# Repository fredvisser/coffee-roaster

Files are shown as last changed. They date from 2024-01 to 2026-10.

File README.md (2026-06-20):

# DIY Hot Air Coffee Roaster

This repository is my latest attempt to make home coffee roasting simple, reliable, scientific, and affordable.

The tagged `v1` release preserves a legacy Nextion-based hardware design. This branch intentionally documents only the current controller, tooling, and firmware layout.

## Features

- PID temperature control with profile-based roast automation
- Dual MAX6675 thermocouple monitoring
- Integrated JC4827W543C touchscreen UI using LVGL
- Web console, REST API, and OTA firmware updates
- Artisan integration for roast logging
- Safety systems for over-temperature, sensor faults, and emergency shutdown

## Firmware Setup

For complete setup, build, and deployment instructions, see [roaster-firmware/README.md](roaster-firmware/README.md).

## Hardware Docs

Hardware assembly guidance and the project bill of materials should live at the repository root because they span the whole build, not just the firmware:

- [BUILD.md](BUILD.md) for the physical build and assembly workflow
- [BOM.md](BOM.md) for the parts list and sourcing notes

The tagged `v1` release remains the reference for the legacy hardware design. This branch should document only the current controller and any current-generation enclosure or PCB assets that are restored into the repository.

### Quick Start

```bash
git clone https://github.com/fredvisser/coffee-roaster.git
cd coffee-roaster/roaster-firmware
./tools/bootstrap.sh
./tools/firmware.sh build --board jc4827w543c
```

Canonical developer entrypoints:

- `./tools/bootstrap.sh`
- `./tools/firmware.sh`
- `./tools/tests.sh`

## Runtime Interfaces

- Web console: `http://roaster-dev.local/console`
- OTA update page: `http://roaster-dev.local/update`
- Profile editor: `http://roaster-dev.local/profile`
- PID workflow: `http://roaster-dev.local/pid`

## Roast Data and Artisan

The firmware can stream roast data to [Artisan](https://artisan-scope.org) over WebSockets. For setup and connection steps, see [ARTISAN.md](ARTISAN.md). The repository includes an Artisan settings file in `Artisan/`.

## Firmware REST API (summary)

For full details see roaster-firmware/README.md. Key endpoints (id-based):

- GET `/api/profiles` → `{ profiles: [{ id, name, active }], active: id }`
- POST `/api/profiles` → Create profile `{ name, setpoints?, activate? }` → returns `{ ok, id, name, setpoints }`
- GET `/api/profiles/:id` → `{ id, name, setpoints, active? }`
- PUT `/api/profiles/:id` → Update `{ name, setpoints, activate? }` (id from path wins)
- POST `/api/profiles/:id/activate` → Activate profile
- DELETE `/api/profiles/:id` → Delete (409 if active)

Notes:
- Times are seconds in API/UI; firmware stores milliseconds.
- Temp bounds 0–500°F; Fan bounds 0–100%.
- Names are display-only; storage is keyed by opaque ids.

## Artisan

For complete Artisan setup, settings import, and connection steps, see [ARTISAN.md](ARTISAN.md).

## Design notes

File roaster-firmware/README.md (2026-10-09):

# Coffee Roaster Firmware

ESP32-S3 JC4827W543C-based coffee roaster control system with PID temperature control, dual fan management, LVGL touchscreen UI, and web interfaces.

## Features

- **Temperature Control**: Dual MAX6675 thermocouple sensors with PID control
- **Heating Element**: PWM-controlled heating element (0-255 range)
- **Dual Fan Control**: 
  - PWM fan for bean agitation
  - BDC fan with servo control for air circulation
- **Local Display**: LVGL-based onboard touchscreen UI on the JC4827W543C panel
- **Network Features**: 
  - WiFi connectivity
  - WebSocket real-time monitoring
  - OTA firmware updates
  - mDNS discovery (roaster-dev.local)
- **Safety Systems**:
  - Thermal runaway protection
  - Over-temperature cutoff (500°F absolute, 460°F roasting)
  - Sensor failure detection
  - Emergency shutdown procedures
  - Hardware watchdog timer
- **Profile Management**: Custom roast profiles with time/temperature/fan curves
- **Persistent Debug Logs**: Appends JSON Lines to the onboard TF/microSD card when available

## Hardware Requirements

- JC4827W543C ESP32-S3 display board
- MAX6675 thermocouple amplifiers (x2)
- Heating element with PWM control circuit
- PWM fan
- BDC fan with servo control
- Integrated local display and touch hardware on the JC4827W543C board
- Optional FAT32-formatted microSD/TF card (8–32 GB)

### TF Card Logging

At boot, the firmware mounts the TF card over SPI using GPIO10 (CS), GPIO11 (MOSI), GPIO12 (clock), and GPIO13 (MISO). Debug entries are appended as JSON Lines with a boot ID and uptime in milliseconds. The active file is `/roaster-debug.jsonl`; up to four 1 MiB rotated segments are retained alongside it. Open `http://roaster-dev.local/console` and choose **Card History** to page through, filter, and download a segment. If the card is absent or cannot be written, the roaster continues using the RAM log buffer and Serial output. Card detection happens at boot, so insert a card before powering on.

## Building

### LVGL Simulator

You can render the display screens locally on macOS using the SDL-backed LVGL simulator:

```bash
brew install cmake pkg-config sdl2

cd roaster-firmware
./tools/lvgl-sim.sh run start
./tools/lvgl-sim.sh screenshot all
```

Screenshot output is written to `roaster-firmware/build/simulator-screens/` and can be inspected directly or shared back into Copilot for visual review.

### Quick Setup (Automated)

```bash
# 1. Navigate to firmware directory
cd roaster-firmware

# 2. Run automated setup script (installs all dependencies)
./tools/bootstrap.sh

# 3. Compile and upload firmware
./tools/firmware.sh upload

# Or just compile (creates .bin in build/ directory)
./tools/firmware.sh build
```

### Manual Setup

#### 1. Install Arduino CLI

```bash
brew install arduino-cli  # macOS
# or download from https://arduino.github.io/arduino-cli/
```

#### 2. Install ESP32 Core

```bash
arduino-cli config init
arduino-cli config add board_manager.additional_urls https://raw.githubusercontent.com/espressif/arduino-esp32/gh-pages/package_esp32_index.json
arduino-cli core update-index
arduino-cli core install esp32:esp32@3.3.11
```

#### 3. Install Required Libraries

```bash
arduino-cli lib install "MAX6675 library" "SimpleTimer" \
  "AutoPID" "ESP32Servo" "ElegantOTA@3.1.7" "ArduinoJson"
```

#### 4. Install AsyncWebServer Libraries (manual)

```bash
cd ~/Documents/Arduino/libraries
git clone https://github.com/ESP32Async/AsyncTCP.git
git clone https://github.com/ESP32Async/ESPAsyncWebServer.git
```

#### 5. Configure ElegantOTA for Async Mode ⚠️ IMPORTANT

ElegantOTA must be configured for async mode to work with ESPAsyncWebServer:

```bash
# Edit ~/Documents/Arduino/libraries/ElegantOTA/src/ElegantOTA.h
# Change: #define ELEGANTOTA_USE_ASYNC_WEBSERVER 0
# To:     #define ELEGANTOTA_USE_ASYNC_WEBSERVER 1

# Or use this one-liner:
sed -i '' 's/#define ELEGANTOTA_USE_ASYNC_WEBSERVER 0/#define ELEGANTOTA_USE_ASYNC_WEBSERVER 1/' ~/Documents/Arduino/libraries/ElegantOTA/src/ElegantOTA.h
```

The automated `./tools/bootstrap.sh` script handles this configuration automatically.

#### 6. Compile and Upload

```bash
# Compile
./tools/firmware.sh build --board jc4827w543c

# Upload
./tools/firmware.sh upload --board jc4827w543c
```

### Build Artifacts

Compiled firmware is automatically copied to `build/roaster-firmware.bin`:

```bash
# Compile firmware (automatically saves .bin to build/)
./tools/firmware.sh build
```

**Note:** `.bin` files are excluded from version control via `.gitignore`.

Builds use all detected CPU cores by default. Set `ROASTER_BUILD_JOBS` to tune
parallel compilation for a constrained machine, for example:

```bash
ROASTER_BUILD_JOBS=4 ./tools/firmware.sh build --board jc4827w543c
```

The firmware revision defaults to the current Git commit. Override it with
`ROASTER_BUILD_VERSION` when a release label or date is required.

## Over-The-Air (OTA) Updates

After initial USB flash, firmware can be updated wirelessly without physical access to the device.

### Accessing OTA Interface

1. Connect to the same WiFi network as the roaster
2. Navigate to: **`http://roaster-dev.local/update`**
   - Alternative: Use device IP address if mDNS doesn't work

### Uploading New Firmware

1. **Compile firmware** to generate `.bin` file:
   ```bash
  ./tools/firmware.sh build
   ```

2. **Access OTA interface** at `http://roaster-dev.local/update`

3. **Upload firmware**:
   - Click "Choose File" and select `build/roaster-firmware.bin`
   - Click "Update"
   - Device will automatically update and reboot (~30 seconds)

4. **Verify update**: Check version or timestamp in debug console

### OTA Best Practices

- ✅ Test firmware on bench hardware before OTA deployment
- ✅ Keep backup `.bin` files of known-good firmware
- ✅ Ensure stable WiFi connection during update
- ✅ Wait for device to fully reboot before reconnecting
- ⚠️ Never interrupt power during OTA update
- ⚠️ OTA updates preserve WiFi credentials and roast profiles

### Helper Scripts

- **`tools/bootstrap.sh`**: Automated dependency installation (arduino-cli required)
- **`tools/firmware.sh`**: Main firmware build, upload, OTA, and monitor entrypoint
  - `./tools/firmware.sh build` - Compile main firmware
  - `./tools/firmware.sh upload` - Compile and upload to a connected board
  - `./tools/firmware.sh run` - Compile, upload, and monitor
  - `./tools/firmware.sh build --board jc4827w543c` - Compile for the JC4827W543C target
- **`tools/tests.sh`**: Named test-suite entrypoint
  - `./tools/tests.sh compile safety` - Compile the safety suite
  - `./tools/tests.sh run pid` - Compile, upload, and monitor the PID suite
- **Legacy aliases**: `./setup_libraries.sh` and `./run_tests.sh` remain available during the transition

## Configuration

Key parameters in `roaster-firmware.ino`:
- `KP`, `KI`, `KD`: PID tuning constants
- `MAX_SAFE_TEMP`: Absolute temperature limit (500°F)
- `MAX_ROAST_TEMP`: Maximum roasting temperature (460°F)
- `COOLING_TARGET_TEMP`: Temperature to complete cooling (145°F)

## Project Structure

```
roaster-firmware/
├── roaster-firmware.ino    # Main firmware sketch
├── src/
│   ├── platform/           # Board config, shared roaster types, calibration types
│   ├── display/            # Display backend selection and adapters
│   ├── profiles/           # RoastProfile model and profile storage logic
│   ├── control/            # PID control, validation, and autotuning
│   ├── network/            # WiFi, OTA, and embedded web UIs
│   ├── integrations/       # External service integrations such as SystemLink
│   └── support/            # Shared support utilities
├── tools/                  # Canonical developer entrypoints
└── tests/                  # Unit and hardware tests
    ├── test_profiles/      # Profile interpolation tests
    ├── test_pid/           # PID controller tests
    ├── test_state_machine/ # State transition tests
    ├── test_safety/        # Safety system tests (CRITICAL)
    ├── hardware_validation/# Hardware-in-the-loop tests
  ├── test_step_response/ # Step response tuning tests
  ├── unit_tests/         # Test runner
  └── wifi_probe/         # Connectivity probe sketch
```

## Testing

Comprehensive test suite covering:
- Profile management and interpolation
- PID controller behavior and stability
- State machine transitions and safety interlocks
- **Critical safety features** (thermal runaway, over-temp, sensor faults)
- Hardware validation tests

```bash
# Show named test suites
./tools/tests.sh list

# Run a test suite
./tools/tests.sh run safety

# Or run individual test suites
./tools/tests.sh run safety --board jc4827w543c
```

See `tests/README.md` for complete testing documentation.

Compatibility note: `./run_tests.sh` and `./setup_libraries.sh` still work, but they now forward to the `tools/` entrypoints.

## Web Profile Editor

- Access at: `http://roaster-dev.local/profile`
- Features:
  - Drag-and-drop points on an interactive graph (time vs temperature)
  - Up to 10 setpoints, each with time (seconds), temperature (°F), fan (%)
  - Save named profiles to NVS; activate and delete from the UI
  - Lists saved profiles and highlights active one
  - Undo/Redo for edits (drag, add, remove, apply)
  - Snapping controls (toggle + step sizes for time/temperature)
  - Import/Export profiles as JSON files

### REST API (id-based)

- GET `/api/profiles`: List all saved profiles
  - Response: `{ profiles: [{ id, name, active }], active: id }`
- POST `/api/profiles`: Create a profile
  - Body: `{ name, setpoints?: [...], activate?: boolean }`
  - Response: `{ ok: true, id, name, setpoints }`
- GET `/api/profiles/:id`: Fetch a saved profile by id
  - Response: `{ id, name, setpoints, active?: boolean }`
- PUT `/api/profiles/:id`: Create/update a profile by id (id from path wins)
  - Body: `{ name, setpoints, activate?: boolean }`
  - Response: `{ ok: true, id, name, setpoints, active?: id }`
- POST `/api/profiles/:id/activate`: Activate a saved profile by id
  - Response: `{ ok: true, active: id, name }`
- DELETE `/api/profiles/:id`: Delete a saved profile (409 if active)

Notes:
- Times are seconds in API/UI; firmware stores milliseconds internally.
- Temp bounds: 0–500°F; Fan bounds: 0–100% (validated server-side).
- Names are display-only; storage is keyed by opaque ids (`pf_<id>` data, `pm_<id>` meta).
- Active profile id is stored under `preferences` key `active_profile_id` for boot-time load.

## Safety

⚠️ **This device controls high temperatures and line voltage.**

All code changes must pass safety tests:
- Thermal runaway protection
- Over-temperature cutoff
- Sensor validation
- Emergency stop capability
- Fail-safe defaults (heater OFF, fan ON)

**Never deploy untested code to hardware that will roast coffee unattended.**

## Documentation

- `../QUICKSTART.md` - Quick start guide
- `../OTA_SETUP.md` - OTA update configuration
- `../agents.md` - Development guidelines
- `tests/README.md` - Testing documentation
- `../CODE_REVIEW.md` - Code review findings and fixes

## Temperature Units

All temperatures in this firmware are in **Fahrenheit (°F)**. This is documented throughout the code to prevent confusion.

## License

See `../LICENSE` or repository root for licensing information.

## Contributing

1. Write tests for new features
2. Ensure all existing tests pass
3. Test safety features thoroughly
4. Update documentation
5. Submit pull request with test results

## Support

For issues, questions, or contributions, see the main repository README.

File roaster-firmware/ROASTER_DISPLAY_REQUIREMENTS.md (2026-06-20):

# Roaster Display Requirements

## Purpose

Define the operator-facing requirements for the onboard roaster display. This document covers the display workflows for roast setup, roast execution, cancellation, cooling, Wi-Fi setup, and profile viewing/selection.

## Scope

The display shall support these operating screens:

- Start
- Network
- Roasting
- Cooling
- Error
- Active Profile

The display requirements apply to any supported display backend. The operator experience should remain consistent whether the implementation is rendered on LVGL hardware or through any future local display backend.

## Design Principles

- The display is the primary local operator interface for starting, monitoring, and canceling a roast.
- The display shall prioritize safety-critical state changes over cosmetic updates.
- The display shall expose profile selection and final-temperature override locally, but full profile authoring remains outside the display UI.
- Local display actions shall not silently corrupt or permanently overwrite saved profiles.

## User Goals

- Select the desired roast profile.
- Review the active profile before starting.
- Set the roast final temperature for the upcoming roast.
- Start a roast from the display without needing the web UI.
- Watch roast progress and key telemetry during roasting.
- Cancel a roast and force a cooling transition.
- Stop cooling and return the machine to idle.
- Configure Wi-Fi credentials and confirm network status.
- Understand error and fault conditions from the display alone.

## Functional Requirements

### FR-1: Start Screen

- The Start screen shall be the default screen when the roaster is idle.
- The Start screen shall display the current bean temperature.
- The Start screen shall display the currently selected profile name.
- The Start screen shall display the configured network address or Wi-Fi status summary.
- The Start screen shall display the firmware revision.
- The Start screen shall display the roast final-temperature target that will be used if the operator starts a roast immediately.
- The Start screen shall provide controls to start a roast, open Wi-Fi configuration, and open the active-profile view.

### FR-2: Final Temperature Setting

- The display shall allow the operator to set or adjust the roast final temperature before starting a roast.
- The display shall show the current value at all times while the roaster is idle.
- The displayed value shall default to the active profile's final target when a profile is loaded or changed.
- The supported range shall be bounded to a safe configured range. The current firmware uses 0-500 F, and the display shall not allow values outside the enforced firmware range.
- Starting a roast shall use the displayed final temperature as the run-time stop target for that roast.
- The final-temperature adjustment shall be treated as a roast-session override unless the operator explicitly saves profile changes through a separate profile-editing flow.

### FR-3: Start Roast

- The display shall allow roast start only when the roaster is in an idle-ready state.
- The display shall block roast start when no valid profile is available.
- The display shall present an explicit error message if the operator attempts to start without a valid profile.
- When a roast is started, the display shall transition to the Roasting screen immediately.
- Starting a roast shall use the active profile for the temperature and fan trajectory.
- Starting a roast shall use the display-selected final-temperature target for roast completion logic.

### FR-4: Roasting Progress

- The Roasting screen shall show the current measured temperature.
- The Roasting screen shall show the current target temperature derived from the active profile.
- The Roasting screen shall show the configured final target temperature.
- The Roasting screen shall show roast progress in time or profile-progress terms.
- The Roasting screen shall show the commanded fan setting.
- The Roasting screen shall show additional run telemetry when available, including heater output, exhaust or fan temperature, and blower drive level.
- Telemetry shall refresh frequently enough for an operator to track roast progression without perceivable lag. A target of at least 1 Hz is required, with faster refresh preferred.

### FR-5: Cancel Roast

- The Roasting screen shall provide a cancel or stop control.
- Canceling a roast shall immediately stop active roast control and de-energize the heater.
- Canceling a roast shall transition the machine into Cooling rather than directly to Idle.
- The system shall record the roast as user-terminated for any downstream logging or reporting path.

### FR-6: Cooling

- The Cooling screen shall show that the roaster is in a cooling state.
- The Cooling screen shall continue to display current temperature.
- The Cooling screen shall show the cooling target or status.
- The Cooling screen shall show that cooling airflow is commanded to maximum or otherwise safe cooling output.
- The Cooling screen shall provide a control to stop cooling and return to Idle when the operator determines it is safe.

### FR-7: Wi-Fi Configuration

- The display shall provide a dedicated Wi-Fi configuration workflow.
- The Network screen shall expose editable fields for SSID and password.
- The Network screen shall provide an apply action.
- While a connection attempt is in progress, the display shall show a transient status such as Connecting.
- After a successful connection, the display shall show the resolved network access address or IP address.
- If no credentials are configured, the display shall show a clear no-network state rather than stale connection data.
- Wi-Fi credentials shall be persisted only after a successful connection attempt.
- Failed connection attempts shall not erase previously working credentials unless the operator explicitly replaces them successfully.

### FR-8: View Active Profile

- The display shall provide an Active Profile screen.
- The Active Profile screen shall show the active profile name.
- The Active Profile screen shall visualize the active roast profile curve.
- The Active Profile screen shall refresh the chart when the active profile changes or when the operator requests a refresh.
- The Active Profile screen shall provide a way to return to the screen for the current machine state.

### FR-9: Switch Profiles

- The display shall allow the operator to switch to the previous or next saved profile from the Active Profile screen.
- Profile switching shall be available only while the roaster is idle.
- Profile switching shall wrap around when the operator moves past the first or last saved profile.
- After a profile change, the display shall update the active profile label, final target temperature, and profile visualization.
- The newly selected profile shall become the active profile used for the next roast.

### FR-10: Error Handling

- The display shall provide a dedicated Error screen.
- The Error screen shall present a short, operator-readable fault message.
- The display shall transition to the Error screen for safety-critical faults such as sensor failure or over-temperature conditions.
- The error presentation shall take precedence over normal navigation until the system enters a safe state.

### FR-11: State-Aware Navigation

- The display shall return to the screen that matches the current machine state when the operator exits auxiliary flows.
- If the roaster is idle, the return destination shall be Start.
- If the roaster is roasting, the return destination shall be Roasting.
- If the roaster is cooling, the return destination shall be Cooling.
- If the roaster is faulted, the return destination shall be Error.

## Out of Scope

- Full roast-profile editing on the display.
- Importing or exporting profiles from the display.
- Advanced PID tuning workflows on the display.
- Historical roast analysis on the display.

## Non-Functional Requirements

- Touch interactions shall be operable with gloved or flour-dusted hands typical of a roasting environment.
- Primary actions such as Start, Stop, and Apply Wi-Fi shall remain visible and understandable without training.
- Safety-related commands shall not depend on network availability.
- The display shall remain usable during background Wi-Fi reconnect attempts.
- Screen transitions and telemetry updates shall not block control-loop timing or watchdog servicing.
- Any backend-specific limitation shall be treated as an implementation gap, not a reason to weaken the operator workflow defined here.

## Acceptance Scenarios

### AS-1: Start a roast with final-temperature override

- Given the roaster is idle and a valid profile is active
- When the operator changes the final temperature and presses Start
- Then the roast starts with the active profile
- And the Roasting screen appears immediately
- And the displayed final target matches the operator-selected override

### AS-2: Cancel an active roast

- Given the roaster is actively roasting
- When the operator presses Stop
- Then the heater output is forced off
- And the machine enters Cooling
- And the Cooling screen is shown

### AS-3: Configure Wi-Fi

- Given the roaster is idle
- When the operator opens the Network screen, enters SSID and password, and presses Apply
- Then the display shows Connecting while the connection is attempted
- And after success the display shows the current network address

### AS-4: Review and switch profiles

- Given the roaster is idle and multiple saved profiles exist
- When the operator opens the Active Profile screen and presses Next or Previous
- Then the active profile changes
- And the profile name, curve, and final target display update to match the new selection

## Implementation Notes

- The current firmware already models the required screens and actions in the display abstraction.
- The current firmware also supports local final-temperature override, profile visualization, idle-only profile cycling, roast stop to cooling, cooling stop to idle, and Wi-Fi credential application.
- A dedicated Network screen is part of the intended requirements even if a specific backend currently routes that action differently.

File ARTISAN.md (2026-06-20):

# Artisan Setup

Use this guide to connect the roaster to [Artisan](https://artisan-scope.org) for live roast logging over WebSockets.

The roaster firmware can stream roast data directly to Artisan once the device is on WiFi and the web interface is reachable.

## What You Need

- a running roaster with current firmware
- WiFi configured on the roaster
- Artisan installed on your computer
- the included settings file at `Artisan/artisan-settings.aset`

## Load The Included Settings

1. Install and open [Artisan](https://artisan-scope.org).
2. Load the included settings file from `Artisan/artisan-settings.aset` using **Help > Load Settings...**.
3. Confirm the loaded device configuration matches the roaster connection.

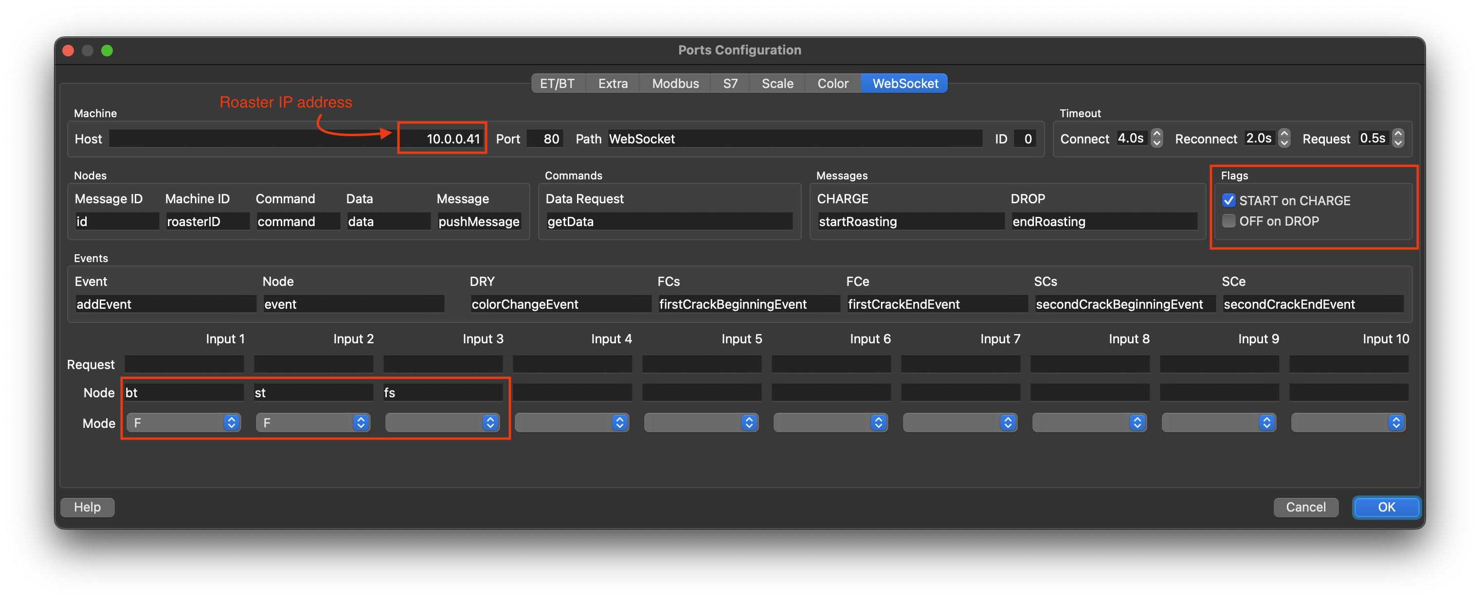
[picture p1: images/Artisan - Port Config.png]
Artisan port configuration


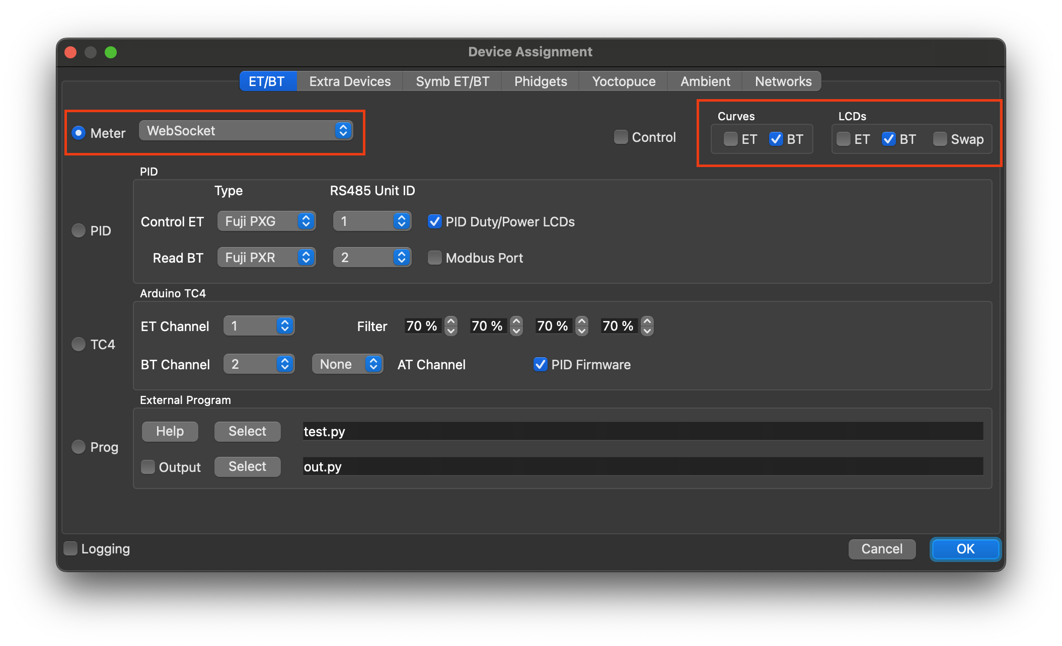
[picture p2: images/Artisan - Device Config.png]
Artisan device configuration


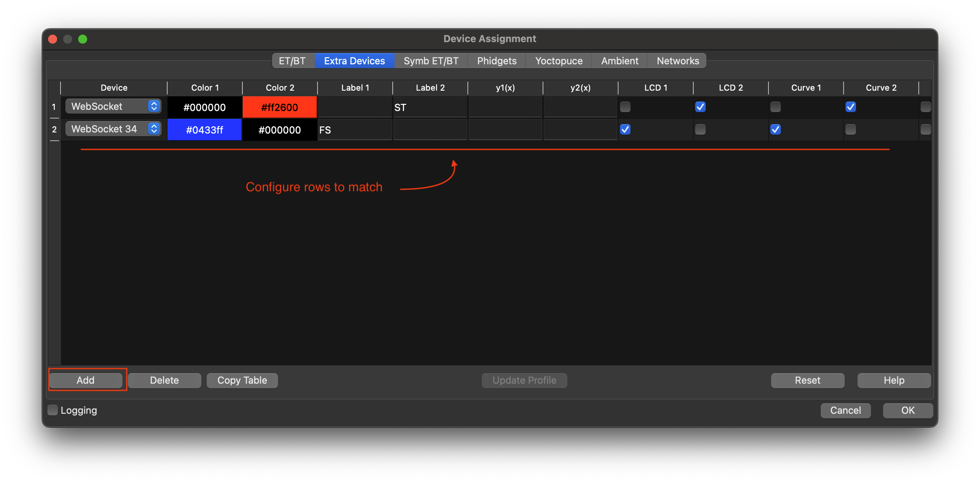
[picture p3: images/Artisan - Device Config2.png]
Artisan device configuration 2


## Connect To The Roaster

1. Make sure the roaster is powered on and connected to your network.
2. In Artisan, enable the connection with the **ON** button.
3. Confirm Artisan shows a successful WebSocket connection and starts receiving temperature data.

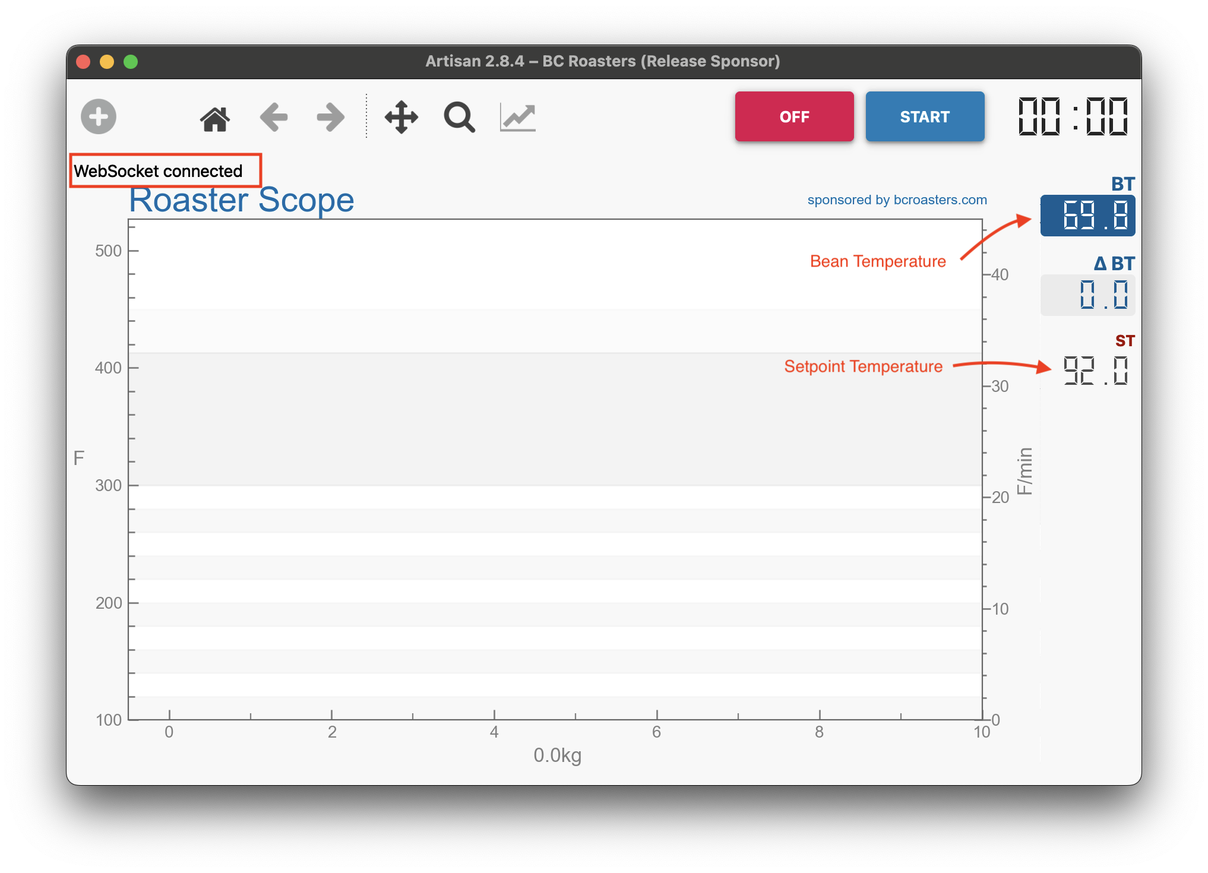
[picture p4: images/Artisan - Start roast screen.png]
Artisan start roast screen


## Start A Roast

1. Start the roast from the roaster UI.
2. Verify Artisan begins recording roast data automatically.
3. Watch the live curve and confirm bean and exhaust values look plausible.

## Troubleshooting

- If Artisan does not connect, verify the roaster web interface is reachable on your network first.
- If the connection succeeds but no useful data appears, confirm the correct settings file was loaded.
- If temperatures look unstable, check thermocouple wiring and the firmware web console before adjusting Artisan.

## Related Files

- [README.md](README.md) for the project overview
- [BUILD.md](BUILD.md) for hardware assembly
- [roaster-firmware/README.md](roaster-firmware/README.md) for firmware workflows

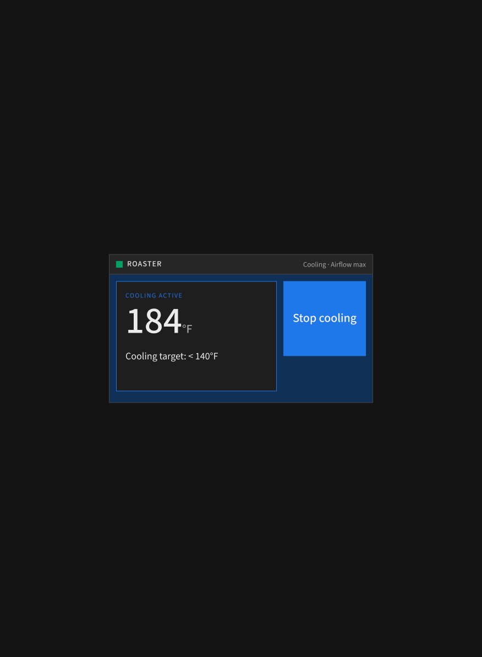
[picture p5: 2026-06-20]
figma-designs/cooling-screen.png

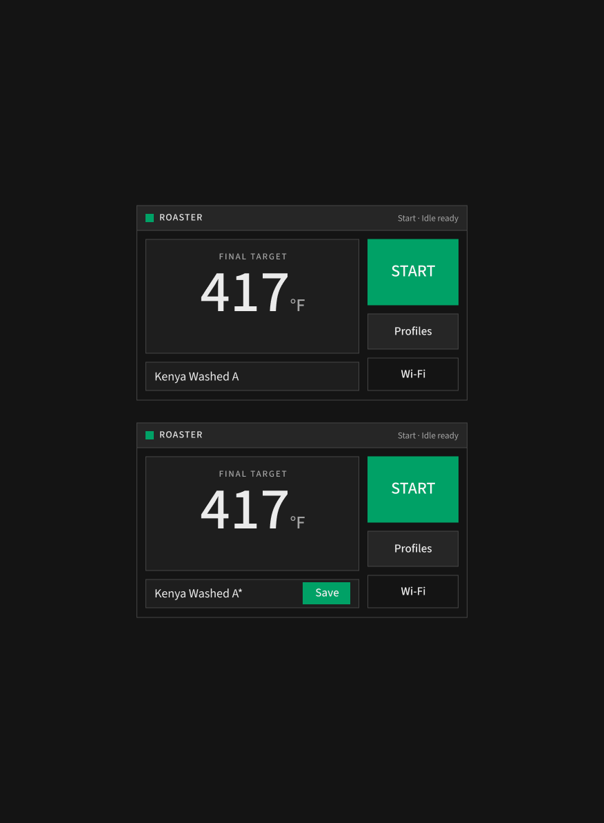
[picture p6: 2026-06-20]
figma-designs/main-screen.png

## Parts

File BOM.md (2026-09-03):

# Bill of Materials

This document is the home for the parts list for the current coffee roaster design.

## Scope

This file describes only the current branch hardware. Legacy parts lists should stay with the tagged `v1` release.

## Build Variants

There are two valid airflow build options for this design.

### Option A: Stock Popper Fan Motor

Use the stock popper fan motor when you want the simplest mechanical build.

- Use a 24 V power supply.
- Use a DC speed controller in the fan power path.
- Connect that speed-control path to the firmware-controlled fan PWM output.

### Option B: Custom Brushless Fan Conversion

Use the custom fan path when replacing the stock motor and fan hardware.

- Print the replacement fan and fan mount in ASA.
- Use a 12 V power supply.
- Use a brushless DC motor and matching controller.
- Treat the custom fan hardware, motor, controller, and 12 V supply as a matched set.

The tables below call out which parts apply to both options and which ones are specific to only one variant.

## Controller And Display Hardware

| Item | Qty | Description | Role | Amazon | AliExpress | Notes |
| --- | ---: | --- | --- | --- | --- | --- |
| JC4827W543C board | 1 | ESP32-S3 display controller with integrated LCD and touch | Main controller and local UI | [Amazon](https://www.amazon.com/dp/B0GTS9XSB4) | [AliExpress](https://www.aliexpress.us/item/3256806543063048.html) | Replaces the old Nano plus Nextion split; verify the capacitive-touch variant, pinout, and onboard memory before ordering |
| Roaster Breakout PCB | 1 | Breakout board from `PCBs/Roaster Breakout/` | Wiring distribution and mounting | N/A | N/A | Message me on Github and I'll mail you one. Alternatively, use `Roaster Breakout.brd` and `Roaster Breakout.sch`, or build the breakout on perf board instead |
| Perf board fallback | 1 | Generic through-hole prototyping board | Manual breakout-board build option | [Amazon](https://www.amazon.com/dp/B072Z7Y19F?ref=ppx_yo2ov_dt_b_fed_asin_title) | TBD | Use this only if not ordering or fabricating a dedicated breakout PCB |
| MAX6675 thermocouple module | 2 | K-type thermocouple amplifier module | Bean and exhaust sensing | [Amazon](https://www.amazon.com/dp/B092ZCSM7J) | [AliExpress](https://www.aliexpress.us/item/3256806044229155.html) | Firmware expects two channels |
| JC IO MX1.25 harness parts | Assorted | 4-pin MX1.25 board-side and harness-side connector parts, with pre-crimped leads | Connects to JC4827W543C I/O | [MX1.25-compatible pre-crimped lead set](https://www.amazon.com/Ssighuyx-Dupont2-54-Connector-Pre-Crimped-Compatible/dp/B0CMZHT1H9) | [MX1.25-compatible connector set](https://www.aliexpress.us/item/3256806948773358.html) | The JC I/O connector is MX1.25, not JST 1.25 or JST GH; verify the pin count, housing/keying, and lead length before ordering |

## Power Electronics

| Item | Qty | Description | Role | Amazon | AliExpress | Notes |
| --- | ---: | --- | --- | --- | --- | --- |
| 24 V power supply | 1 | Main low-voltage supply | Required for the stock popper fan motor build | TBD | [AliExpress](https://www.aliexpress.us/item/3256805366654681.html) | Option A only |
| 12 V power supply | 1 | Main low-voltage supply for custom fan conversion | Powers the brushless fan path | [Amazon](https://www.amazon.com/dp/B078RY6YY3?ref=ppx_yo2ov_dt_b_fed_asin_title) | [AliExpress](https://www.aliexpress.us/item/3256805366654681.html) | Option B only; confirm the ordered voltage and current variant |
| DC-DC converter or regulator | 1 | Secondary low-voltage conversion stage | Supplies any required rail below the main supply voltage | TBD | TBD | Keep exact part aligned with the restored current board design |
| Heater SSR | 1 | AC-output solid-state relay | Controls heater power | [Amazon](https://www.amazon.com/SSR-25DA-3-32VDC-Output-24-480VAC-Plastic/dp/B08GPJ1V2J) | [AliExpress](https://www.aliexpress.us/item/2255800713623525.html) | Must be correctly rated for mains and heater load |
| DC speed controller for stock fan motor | 1 | MOSFET-based DC motor speed controller | Controls the stock popper fan motor path from the PWM-controlled output | [Amazon](https://www.amazon.com/Anmbest-High-Power-Adjustment-Electronic-Brightness/dp/B07NWD8W26) | TBD | Option A only; select a specific controller listing after confirming the stock motor voltage and current |
| Power inlet or socket assembly | 1 | Enclosed mains input | Safe power entry | [Amazon](https://www.amazon.com/dp/B07PVP8CLT?ref_=ppx_hzsearch_conn_dt_b_fed_asin_title_31&th=1) | TBD | The popper lamp cord can be reused for outlet, switch, and power-supply wiring |
| Power switch | 1 | Panel-style rocker or toggle switch | Main power control | [Amazon](https://www.amazon.com/dp/B09YCG3NM1?ref=ppx_yo2ov_dt_b_fed_asin_title) | TBD | Clip off the flexible plastic tabs and super glue the switch to the case to avoid overstressing the printed enclosure |

## Sensors And Wiring

| Item | Qty | Description | Role | Amazon | AliExpress | Notes |
| --- | ---: | --- | --- | --- | --- | --- |
| K-type thermocouple | 2 | Temperature probes | Bean and exhaust temperature measurement | [Amazon](https://www.amazon.com/dp/B092ZCSM7J?ref=ppx_yo2ov_dt_b_fed_asin_title) | [AliExpress](https://www.aliexpress.us/item/3256806044229155.html) | Carefully hacksaw roughly 3/16 in off the tip to expose the junction so the probe responds faster to moving air |
| Silicone wire | Assorted | High-temp flexible wire | Heater and fan rewiring | [Amazon](https://www.amazon.com/dp/B07FMLVF84?ref=ppx_yo2ov_dt_b_fed_asin_title) | [AliExpress](https://www.aliexpress.us/item/2255800441309579.html) | Use the popper lamp cord for outlet, switch, and supply wiring; use higher-temp silicone wire for motor and heater wiring |
| Splice or crimp connectors | Assorted | Inline electrical splice terminals | Joins motor, heater, and supply wiring | [Amazon](https://www.amazon.com/dp/B0CJ5QF3VX?ref=ppx_yo2ov_dt_b_fed_asin_title) and [Amazon](https://www.amazon.com/Feggizuli-Connectors-Connector-Terminals-Electrical/dp/B0B4H54KPS) | TBD | Use these or equivalent crimp connectors where removable or insulated splices are needed |
| Heat shrink tubing | Assorted | Wire insulation and strain relief | Safer harness construction | TBD | TBD | Use on all splices and terminations where practical |

## Airflow And Load Hardware

| Item | Qty | Description | Role | Amazon | AliExpress | Notes |
| --- | ---: | --- | --- | --- | --- | --- |
| 1200 W popcorn popper | 1 | Upright hot-air popcorn popper with a clear upper chamber and side switch | Core roasting hardware | [Amazon](https://a.co/d/01RdS3ub) | TBD | Modified for external heater and fan control. If this listing is out of stock, find another hot-air popper that looks the same. |
| Stock popper fan motor | 1 | Original motor retained from the popper | Airflow source | Included with popper | N/A | Option A only |
| Brushless DC motor and controller | 1 set | Replacement motor and matched driver | Airflow source for custom fan conversion | [Amazon](https://www.amazon.com/dp/B075ZSDR2T?ref=ppx_yo2ov_dt_b_fed_asin_title) | TBD | Option B only |

## Mechanical And Printed Parts

| Item | Qty | Description | Role | Amazon | AliExpress | Notes |
| --- | ---: | --- | --- | --- | --- | --- |
| Enclosure Bottom.stl | 1 | Main lower enclosure body | Supports popper base and internal hardware | N/A | N/A | Current filename in `3D printing/` |
| Enclosure Top.stl | 1 | Upper enclosure shell | Covers and protects internal hardware | N/A | N/A | Current filename in `3D printing/` |
| Handle - Main.stl | 1 | Main carrying handle | Mechanical handling | N/A | N/A | Current filename in `3D printing/` |
| Handle - Trim.stl | 1 | Cosmetic or fit trim for handle | Finish and fit | N/A | N/A | Current filename in `3D printing/` |
| 12V - Power Supply Mount.stl | 1 | Printed mount for the power supply | Internal mechanical support | N/A | N/A | Current filename in `3D printing/`; verify fit for the selected supply |
| Breakout Mount.stl | 1 | Printed mount for the breakout board | Supports controller-side hardware | N/A | N/A | Current filename in `3D printing/` |
| Feet.stl | 1 set | Printed feet | Stability and surface protection | N/A | N/A | Current filename in `3D printing/`; TPU is still a good default |
| BDC Fan Mount.stl | 1 | Printed fan mount for the custom airflow option | Supports the brushless motor conversion | N/A | N/A | Option B only |
| Fan.stl | 1 | Printed fan for the custom airflow option | Airflow hardware for the brushless conversion | N/A | N/A | Option B only; print in ASA |
| Roaster Enclosure v2.3mf | 1 | Combined enclosure project file | Print preparation and fit reference | N/A | N/A | Use this to inspect the assembled print set before slicing |
| Roaster Breakout.brd and Roaster Breakout.sch | 1 set | Current breakout board design files | Board fabrication and reference | N/A | N/A | Located in `PCBs/Roaster Breakout/` |

## Fasteners And Consumables

| Item | Qty | Description | Role | Amazon | AliExpress | Notes |
| --- | ---: | --- | --- | --- | --- | --- |
| M3 fastener kit | 1 set | Assorted M3 screws, nuts, and standoffs | Standard enclosure and electronics fasteners | [M3 fastener set](https://www.amazon.com/dp/B097Y6KCVW?ref_=ppx_hzsearch_conn_dt_b_fed_asin_title_3) | TBD | Use M3 hardware as the standard fastener set wherever practical |
| M4 nuts and bolts | Assorted | Popper base and enclosure mounting hardware | Mechanical attachment of the popper assembly | TBD | TBD | Legacy assembly used M4 hardware through the enclosure bottom |
| Heat shrink and cable management | Assorted | Insulation and strain relief | Safer wiring | TBD | TBD | Strongly recommended |
| Super glue or equivalent adhesive | As needed | Adhesive for low-load mounting tasks | Switch and trim attachment | TBD | TBD | Use to mount the power switch after clipping the plastic tabs; use only where heat exposure is acceptable |

## Remaining Gaps

The core v2 parts list is in place, but a few sourcing fields still need confirmation before this BOM is fully complete:

- remaining Amazon and AliExpress links still marked `TBD`
- final quantities for connectors, heat shrink, and some fasteners
- any additional board-fabrication outputs you want listed beyond `Roaster Breakout.brd` and `Roaster Breakout.sch`

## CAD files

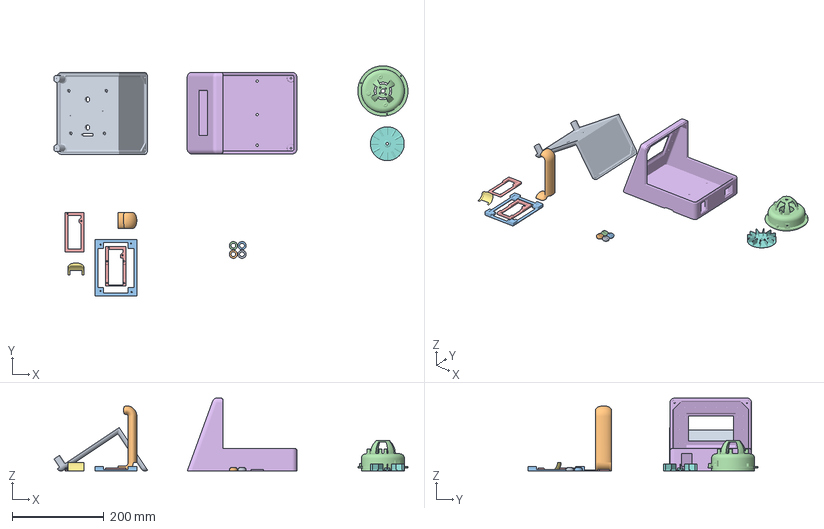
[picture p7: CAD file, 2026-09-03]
3D printing/Roaster Enclosure v2.3mf
770.8 x 501.4 x 158.8 mm
Enclosure Top
Handle - Main.step.stl
12V - Power Supply Mount - 12V - Power supply mount.step
Part Studio 1 - Part 1-58.step
Breakout Mount - Perfboard.step
Enclosure - Enclosure Bottom-2.step
Handle - Trim.stl
Part Studio 1 - Fan-7.step
Feet.stl x 4
Breakout mount - PCB

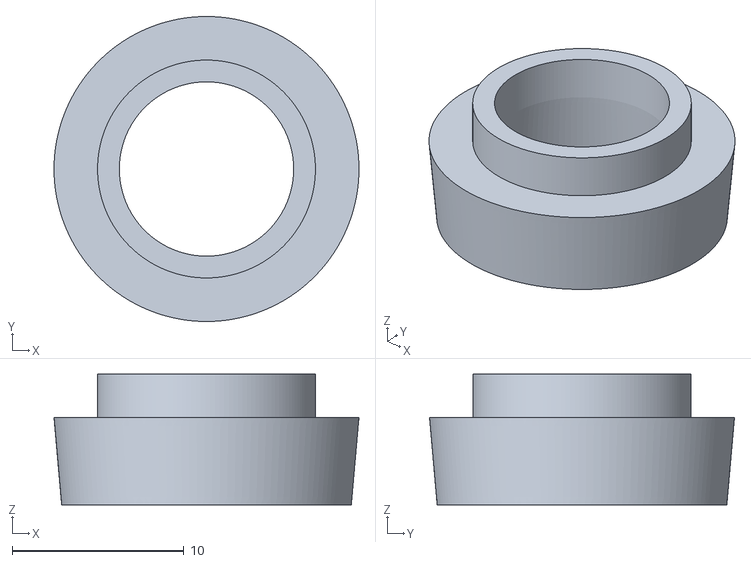
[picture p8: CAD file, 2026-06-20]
3D printing/Feet.stl
17.8 x 17.8 x 7.62

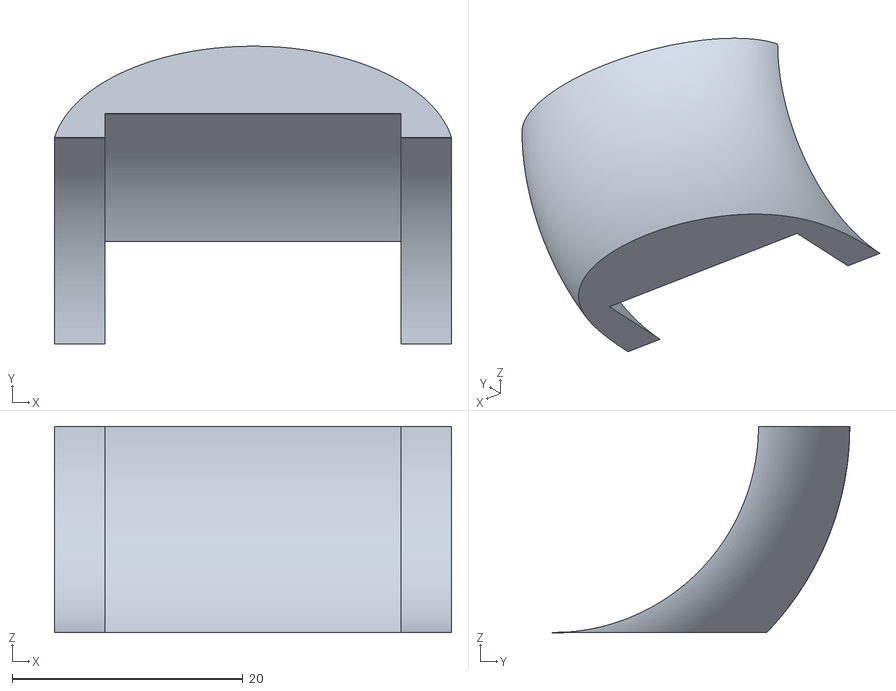
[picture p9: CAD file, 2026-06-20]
3D printing/Handle - Trim.stl
34.4 x 25.8 x 17.9

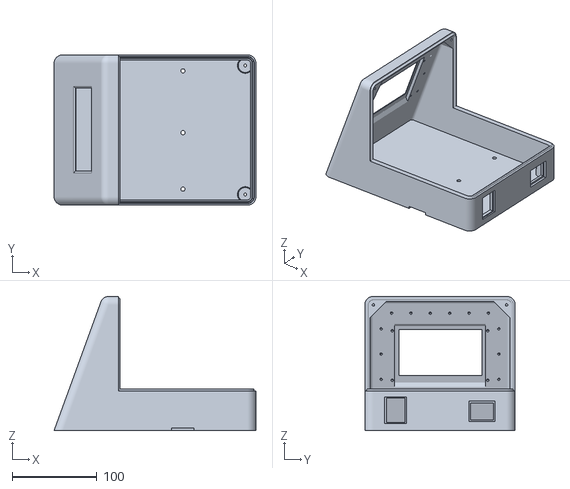
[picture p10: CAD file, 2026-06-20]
3D printing/Enclosure Bottom.stl
238.8 x 177.8 x 158.8

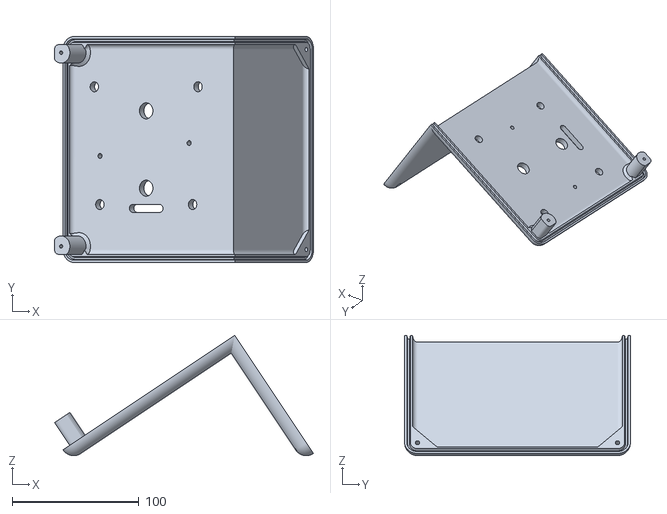
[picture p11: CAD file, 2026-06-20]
3D printing/Enclosure Top.stl
203.9 x 177.8 x 94.7

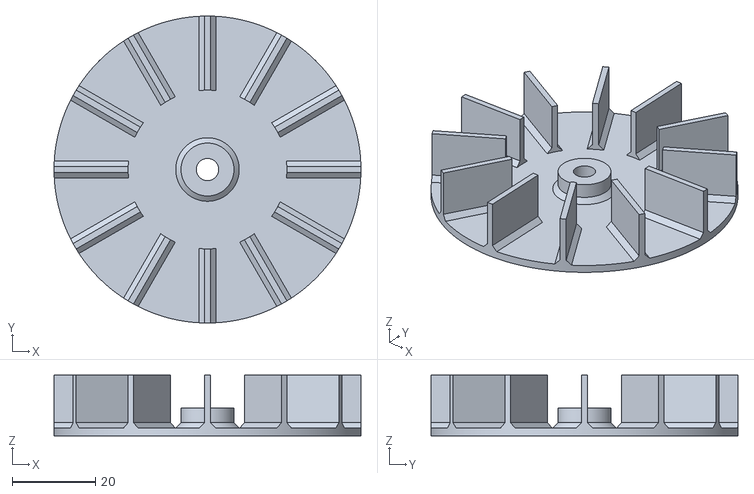
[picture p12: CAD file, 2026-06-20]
3D printing/Fan.stl
73.7 x 73.7 x 14.6

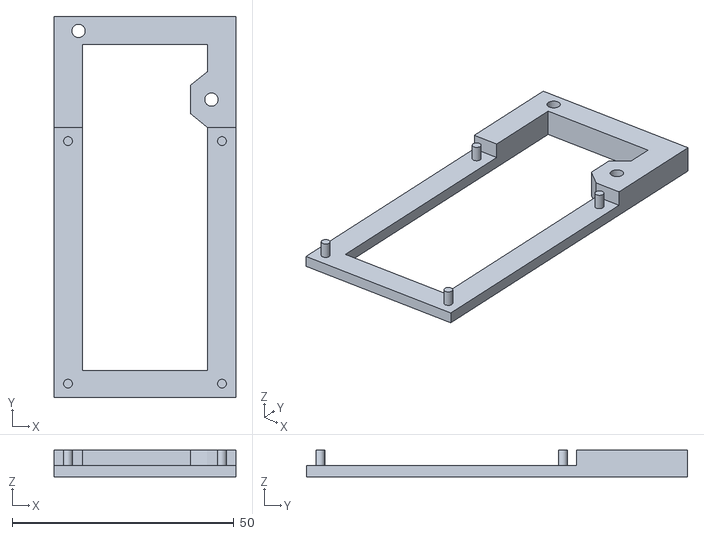
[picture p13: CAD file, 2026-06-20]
3D printing/Breakout Mount.stl
41.0 x 86.0 x 6.00

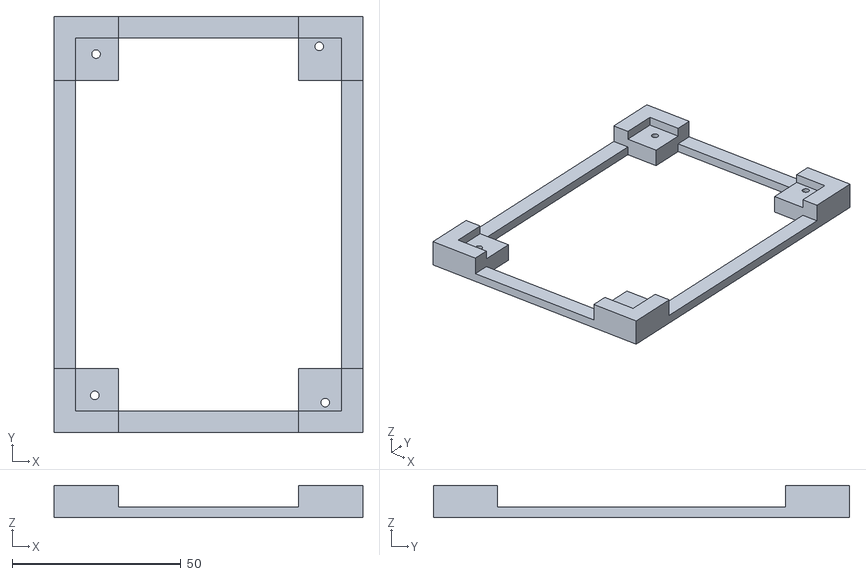
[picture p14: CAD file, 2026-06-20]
3D printing/12V - Power Supply Mount.stl
91.4 x 123.2 x 9.52

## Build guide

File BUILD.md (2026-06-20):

# Hardware Build Guide

Use this guide to assemble the current JC4827W543C-based coffee roaster. Use [BOM.md](BOM.md) for the parts list and sourcing links. Use [roaster-firmware/README.md](roaster-firmware/README.md) for firmware installation, OTA updates, and test workflows.

## Before You Start

This project combines mains voltage, high temperatures, and moving parts. Build it only if you are comfortable with basic electrical work and safe mains wiring practices.

- Never power the heater unattended.
- Keep mains wiring separated from low-voltage wiring.
- Use insulated connectors, heat shrink, and an enclosed mains inlet.
- Verify heater-off fail-safe behavior before the first roast.
- Keep a fire extinguisher nearby during bring-up and testing.

## Choose Your Fan Build

You need to decide which airflow build you are making before ordering parts or wiring the controller.

### Option A: Stock Popper Fan Motor

Choose this if you want the simplest mechanical build.

- Keep the stock popper fan motor.
- Use a 24 V power supply.
- Use the DC speed controller listed in [BOM.md](BOM.md).
- Connect the speed controller to the firmware-controlled fan PWM output.

### Option B: Custom Brushless Fan Conversion

Choose this if you want to replace the stock fan hardware.

- Print the replacement fan and fan mount in ASA.
- Use a 12 V power supply.
- Use the brushless DC motor and controller listed in [BOM.md](BOM.md).
- Treat the fan, mount, motor, controller, and 12 V supply as one matched system.

## What You Are Building

The current roaster uses:

- a JC4827W543C ESP32-S3 display board for the controller and touchscreen UI
- two MAX6675 thermocouple modules for bean and exhaust temperature
- one popcorn popper modified for separate heater and fan control
- one AC SSR in the heater path
- one main low-voltage supply, either 24 V or 12 V depending on the fan build

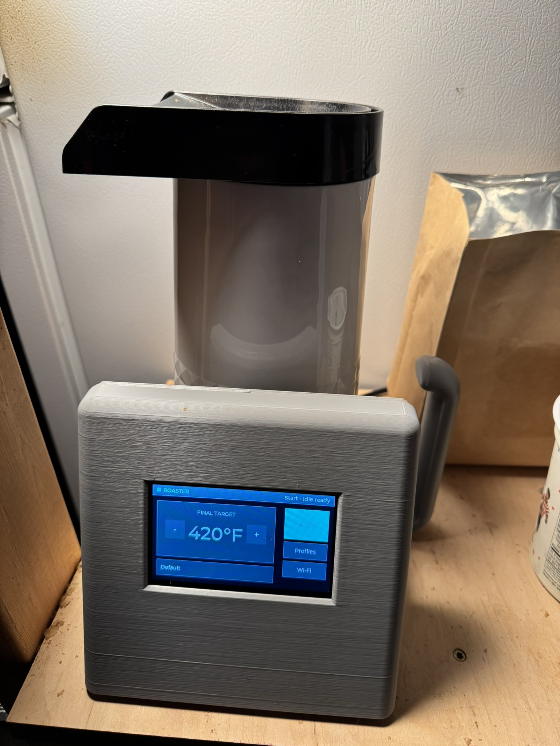
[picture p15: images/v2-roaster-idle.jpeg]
Assembled roaster

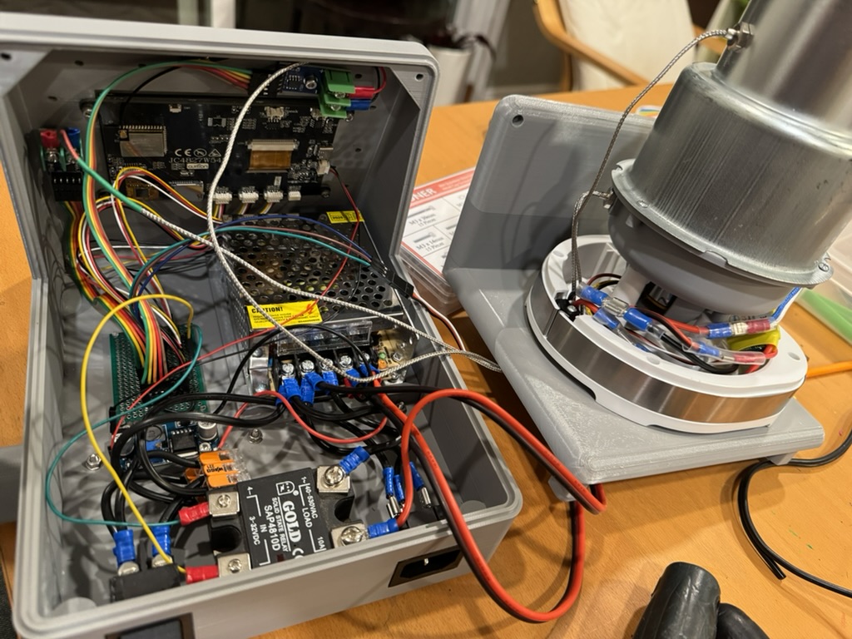
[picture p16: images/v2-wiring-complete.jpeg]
Assembled roaster internals


## Tools And Consumables

Have these on hand before starting:

- screwdrivers, hex keys, pliers, and flush cutters
- soldering iron and solder
- drill and bits for thermocouple and mounting holes
- heat shrink and crimp or splice connectors
- silicone-insulated wire for heater and fan rewiring
- super glue for the power switch and other light-duty mounting tasks
- fasteners and printed parts from [BOM.md](BOM.md)

## Step 1: Print The Parts

Print or obtain the enclosure parts before modifying the popper.

Print the parts from the `3D printing/` folder. The current filenames are:

- `Enclosure Bottom.stl`
- `Enclosure Top.stl`
- `Handle - Main.stl`
- `Handle - Trim.stl`
- `12V - Power Supply Mount.stl`
- `Breakout Mount.stl`
- `Feet.stl`
- `BDC Fan Mount.stl`
- `Fan.stl`
- `Roaster Enclosure v2.3mf`

Recommended materials:

- PLA for enclosure parts away from concentrated heat
- TPU for feet
- ASA for the custom fan and fan mount if you are building Option B

Use `Roaster Enclosure v2.3mf` as the assembled project file if you want to inspect the overall print set before slicing individual STL files.

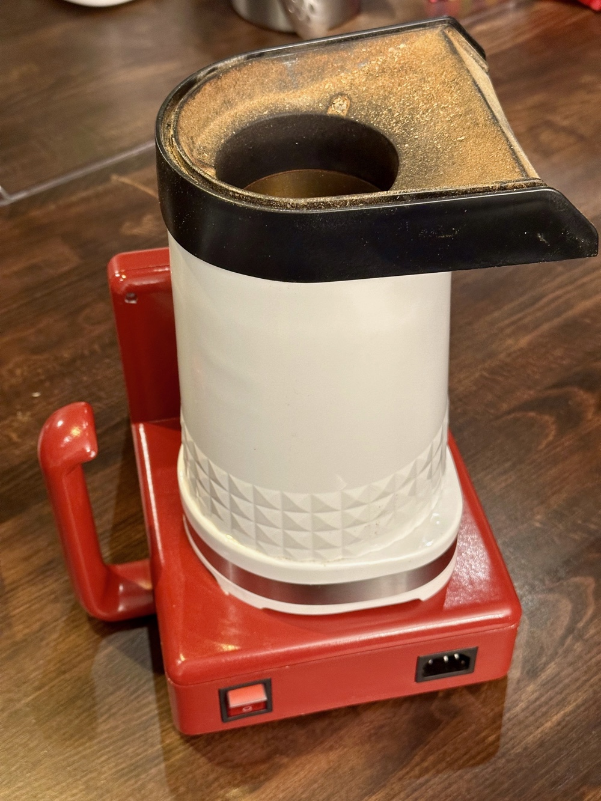
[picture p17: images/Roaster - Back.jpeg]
Roaster back view


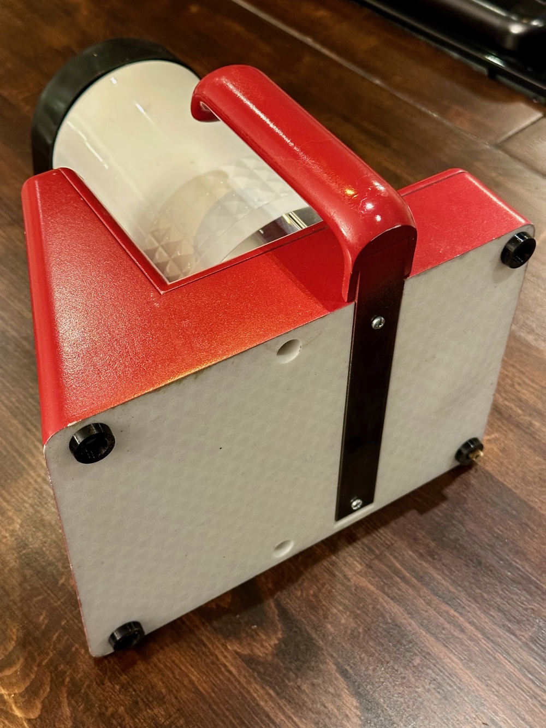
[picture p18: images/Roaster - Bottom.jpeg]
Roaster bottom view


Before moving on, test fit the display opening, mounting bosses, power supply mount, and wire-routing paths.

## Step 2: Build The Controller Hardware

Assemble the controller-side hardware next.

You will need:

- the JC4827W543C display board
- two MAX6675 modules
- the heater SSR
- the selected fan-control hardware for your build option
- the mains inlet and power switch
- the low-voltage power supply
- either the project breakout PCB or a perf-board equivalent

The breakout-board files currently in the repository are:

- `PCBs/Roaster Breakout/Roaster Breakout.sch`
- `PCBs/Roaster Breakout/Roaster Breakout.brd`
- `PCBs/Roaster Breakout/Breakout Perfboard.diy`

Mount the controller components so that:

- the display board is secure and accessible
- the thermocouple modules are reachable for wiring and service
- the heater control path is clearly separated from signal wiring
- the low-voltage supply and breakout hardware have adequate clearance

If you are making a breakout board on perf board, finish that assembly before starting the enclosure wiring.

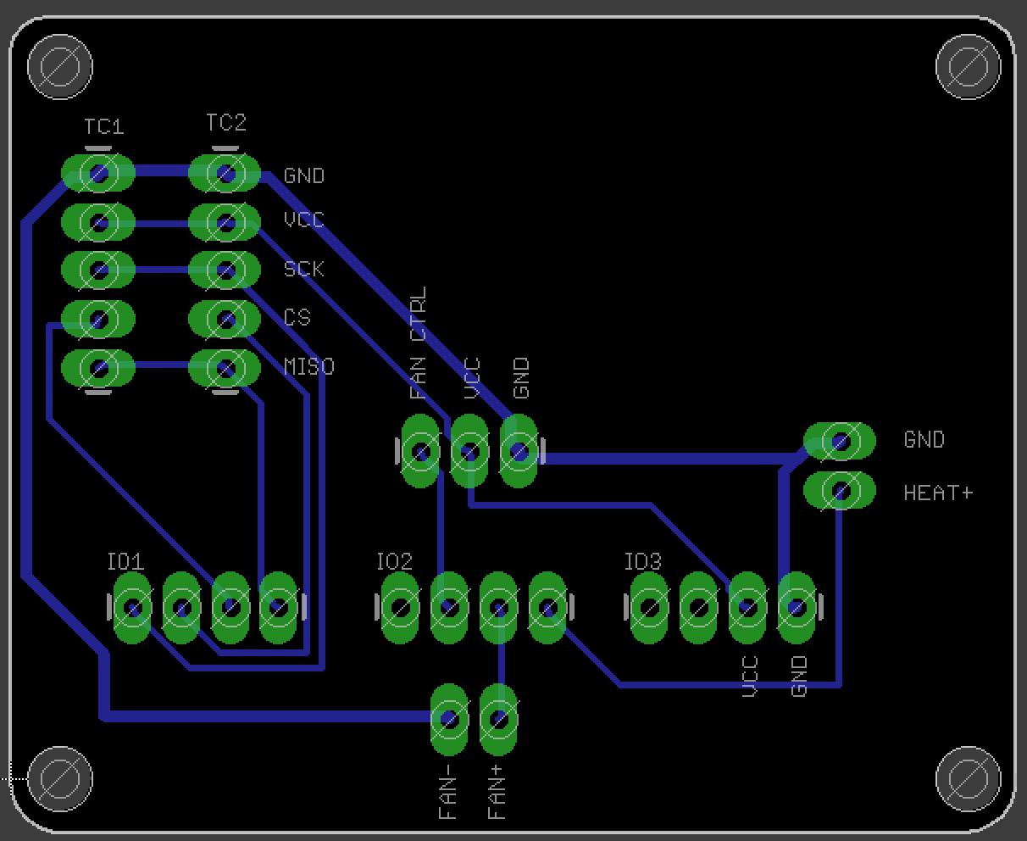
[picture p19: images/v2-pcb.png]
Roaster breakout PCB


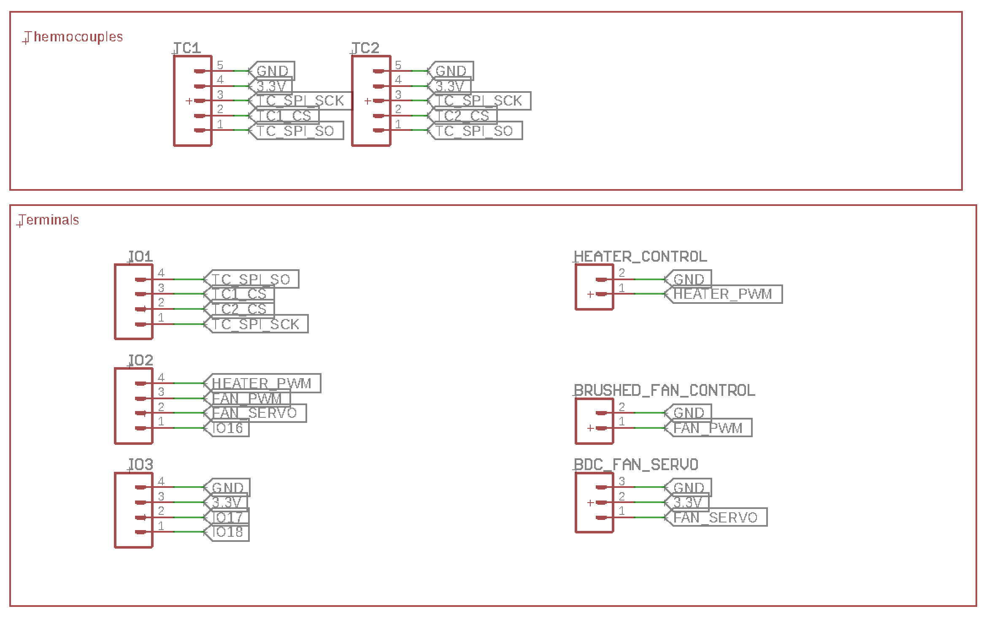
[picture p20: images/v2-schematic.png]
Roaster breakout schematic


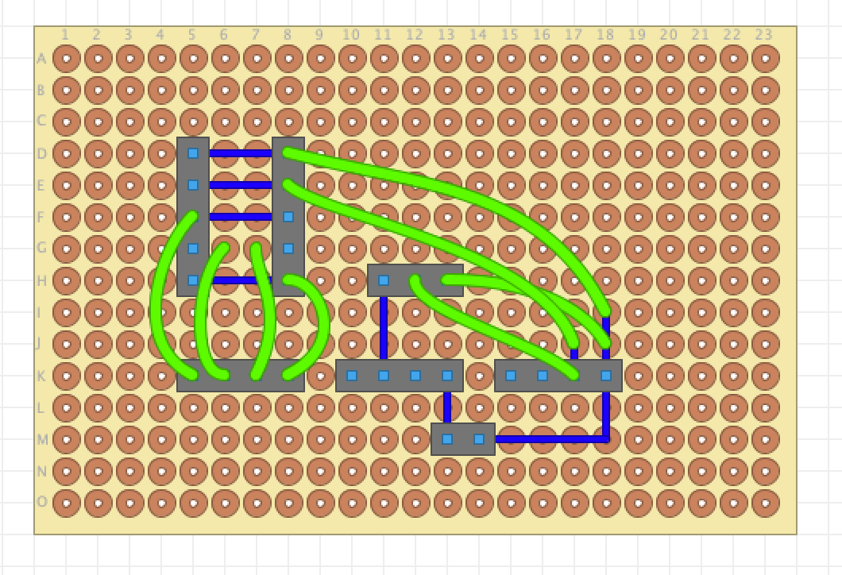
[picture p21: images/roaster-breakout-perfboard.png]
Perfboard breakout example


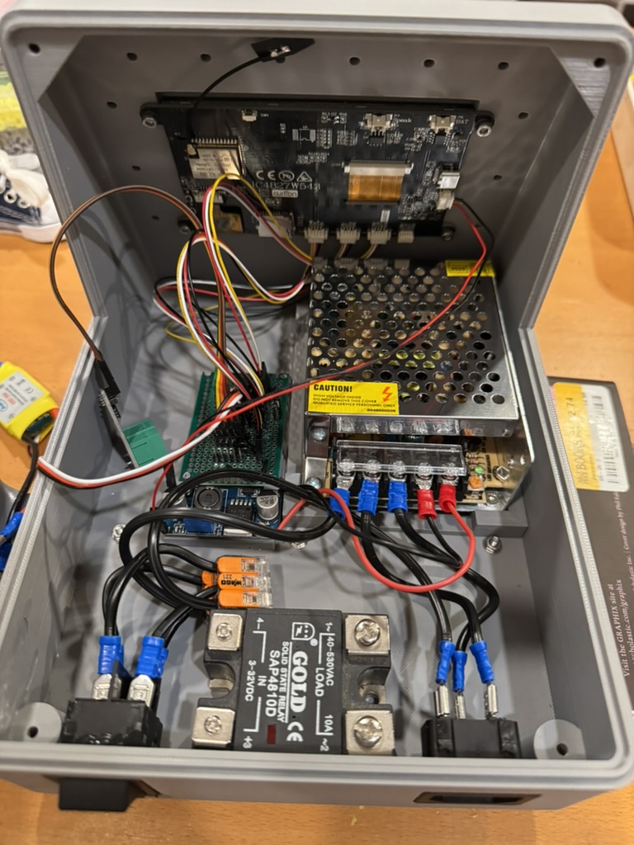
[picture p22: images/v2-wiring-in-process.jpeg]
Controller hardware layout


## Step 3: Modify The Popcorn Popper

Modify the popper in this order.

1. Remove the screws from the bottom of the popper.
2. Lift the popper core out of the base.
3. Remove the stock fan-motor diode wiring and separate the heater connections.
4. Remove or bypass the stock thermal cutout behavior used for stand-alone popper operation.
5. Rewire the fan and heater for external control.
6. Drill the roasting chamber and install the thermocouples.
7. Reassemble the popper core into the base.
8. Route the modified wiring so it can exit cleanly into the enclosure.

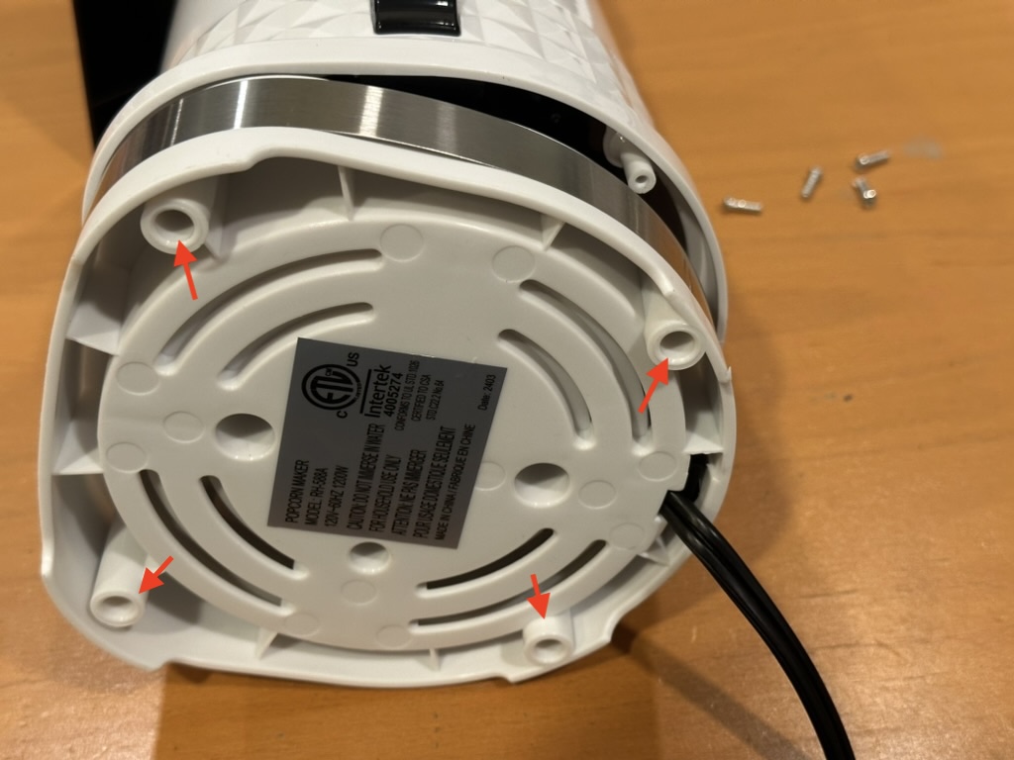
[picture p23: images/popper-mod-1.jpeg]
Popper disassembly step 1


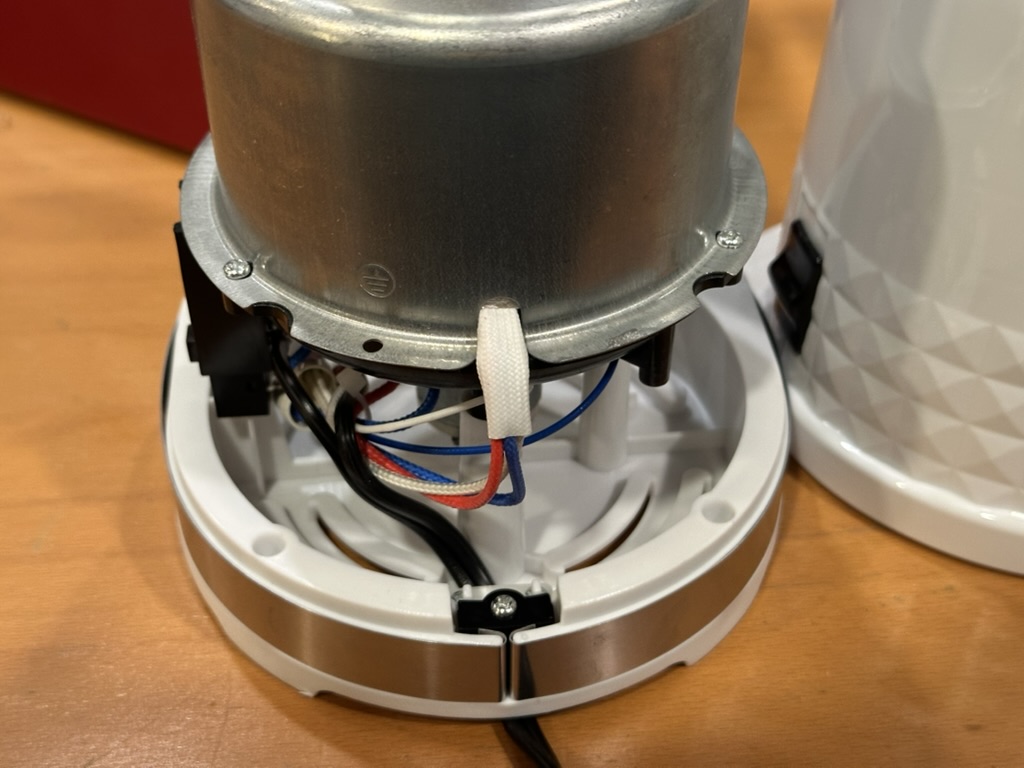
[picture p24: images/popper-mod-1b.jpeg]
Popper disassembly step 1b


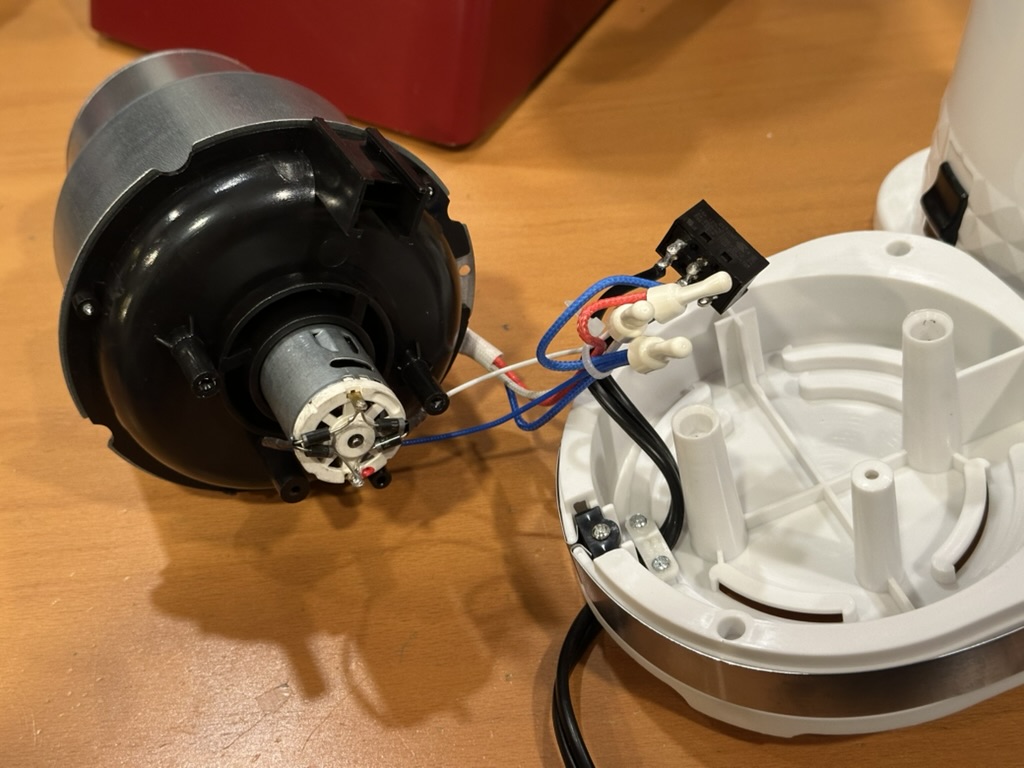
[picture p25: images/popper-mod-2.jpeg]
Popper disassembly step 2


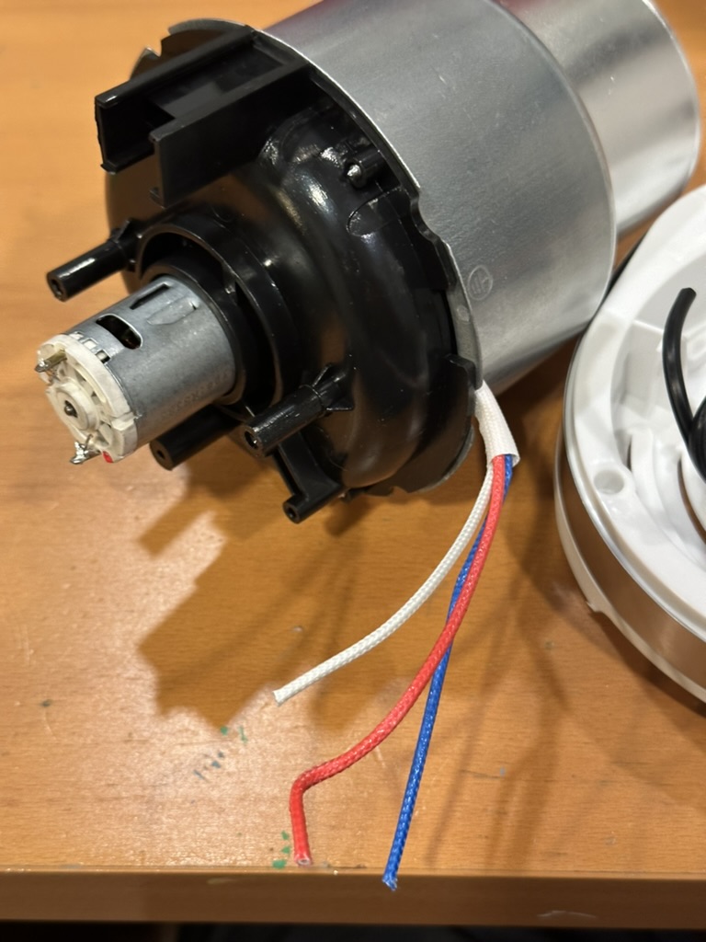
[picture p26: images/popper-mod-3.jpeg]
Popper disassembly step 3


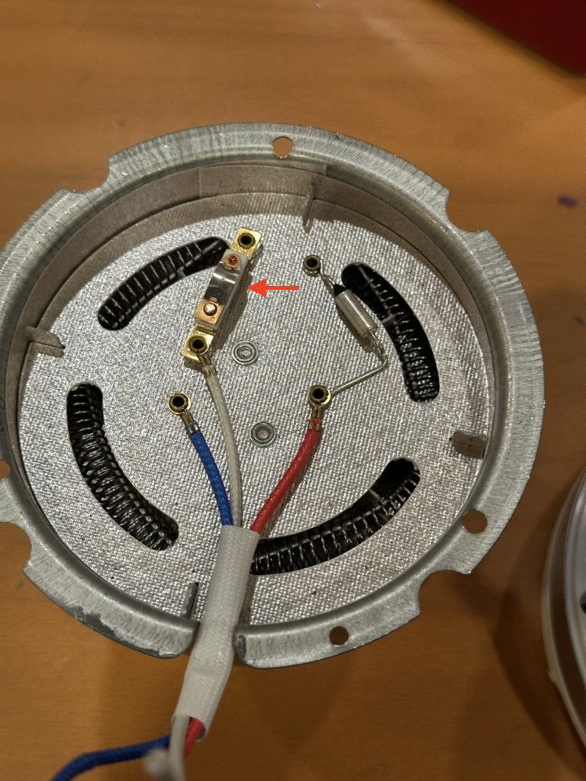
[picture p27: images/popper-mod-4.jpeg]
Popper disassembly step 4


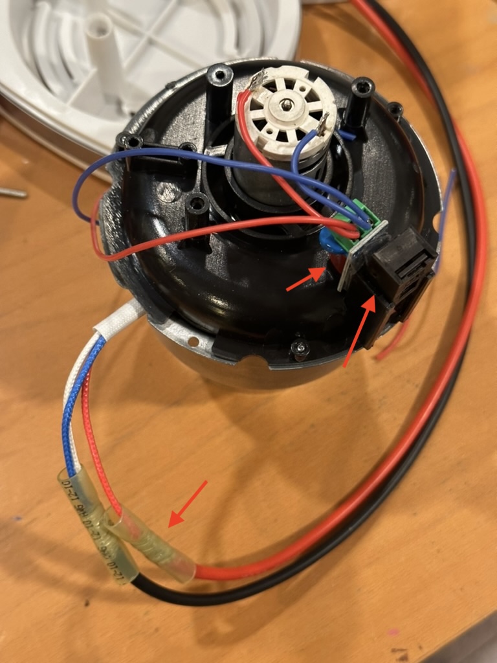
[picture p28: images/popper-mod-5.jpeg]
Popper rewiring step


Important details:

- Use the updated popper model listed in [BOM.md](BOM.md).
- Use the original popper lamp cord for outlet, switch, and power-supply wiring if it is in good condition.
- Use higher-temperature silicone wire for the motor and heater wiring.
- Keep thermocouple wiring away from switched heater and motor wiring to reduce noise.

### Thermocouple Preparation

Before installing the thermocouples, carefully cut about 3/16 in from the probe tip with a hacksaw so the thermocouple junction is exposed. This makes the probe more responsive to moving air inside the roasting chamber.

Mount the probe so the tip is in the process air stream, not buried inside a closed metal sleeve.

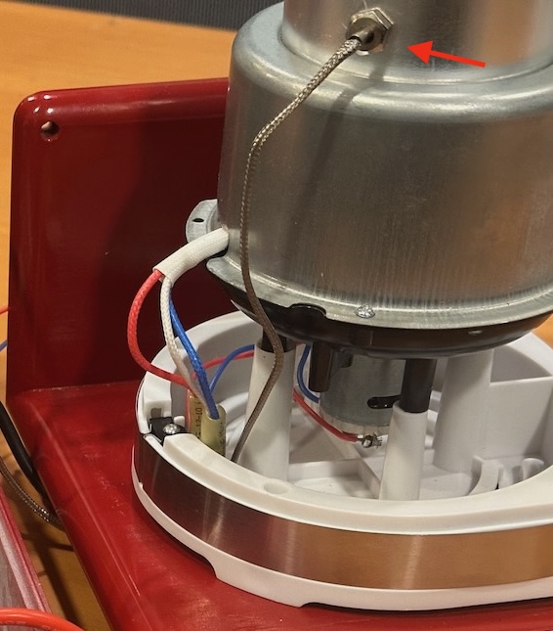
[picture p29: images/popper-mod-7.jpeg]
Thermocouple installation


## Step 4: Assemble The Enclosure

Once the printed parts, controller hardware, and modified popper are ready, assemble the enclosure.

1. Install the feet, breakout mount, and power-supply mount.
2. Mount the popper base to the enclosure bottom.
3. Mount the display board, breakout hardware, SSR, power supply, and thermocouple modules.
4. Mount the mains inlet and power switch.
5. Fit the handle and trim pieces.

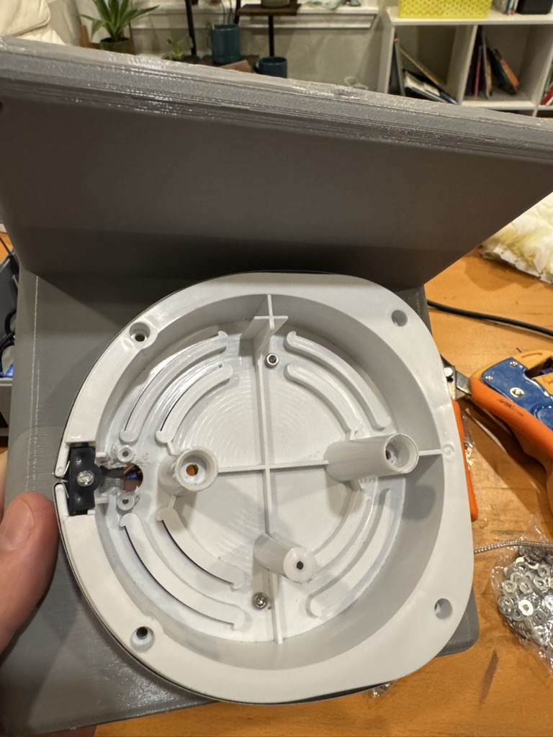
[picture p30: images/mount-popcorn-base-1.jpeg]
Mount the popper base


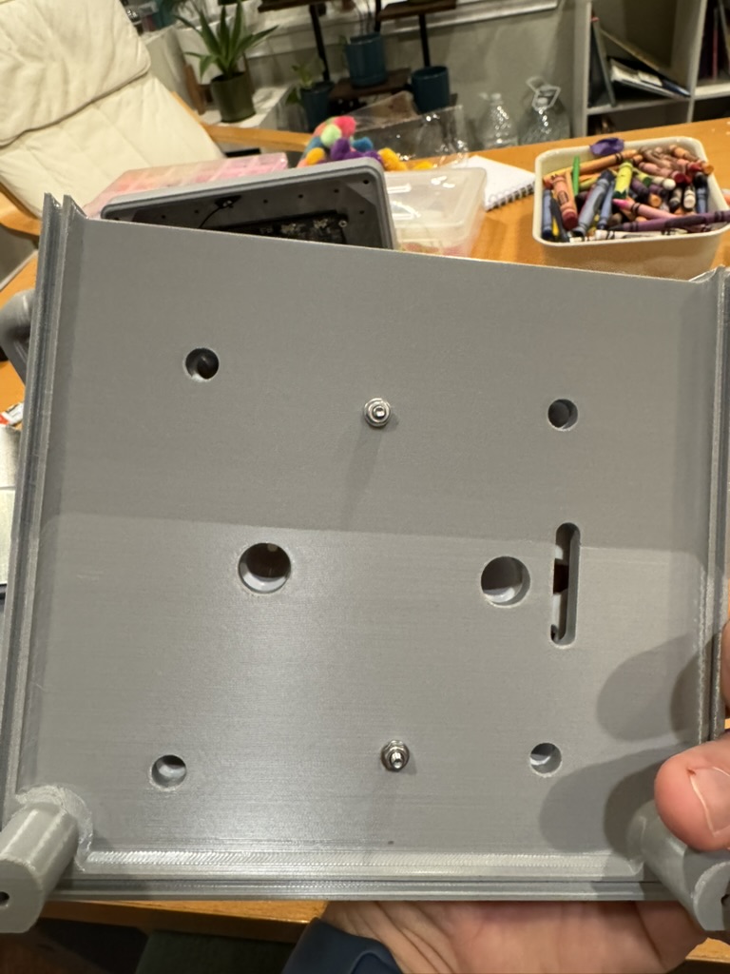
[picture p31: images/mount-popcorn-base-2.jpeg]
Mount the popper base detail


Assembly layout reference

Power switch note:

- Clip off the flexible plastic tabs on the switch before installation.
- Super glue the switch to the case instead of forcing the tabs into the printed wall.
- This reduces stress on the enclosure and makes the switch easier to mount cleanly.

Before continuing, confirm that the internal components clear the enclosure walls and that the popper mounting hardware does not interfere with the controller hardware.

## Step 5: Wire The Roaster

Wire the system carefully and deliberately.

1. Run mains wiring for the inlet, switch, heater SSR, and power supply.
2. Run low-voltage wiring for the controller, thermocouple modules, and fan-control hardware.
3. Connect the heater through the AC SSR.
4. Connect the fan-control path for your chosen build option.
5. Connect both thermocouples to their MAX6675 modules.
6. Connect the JC4827W543C board I/O using the harness parts listed in [BOM.md](BOM.md).
7. Secure and strain-relieve all wiring before closing the enclosure.

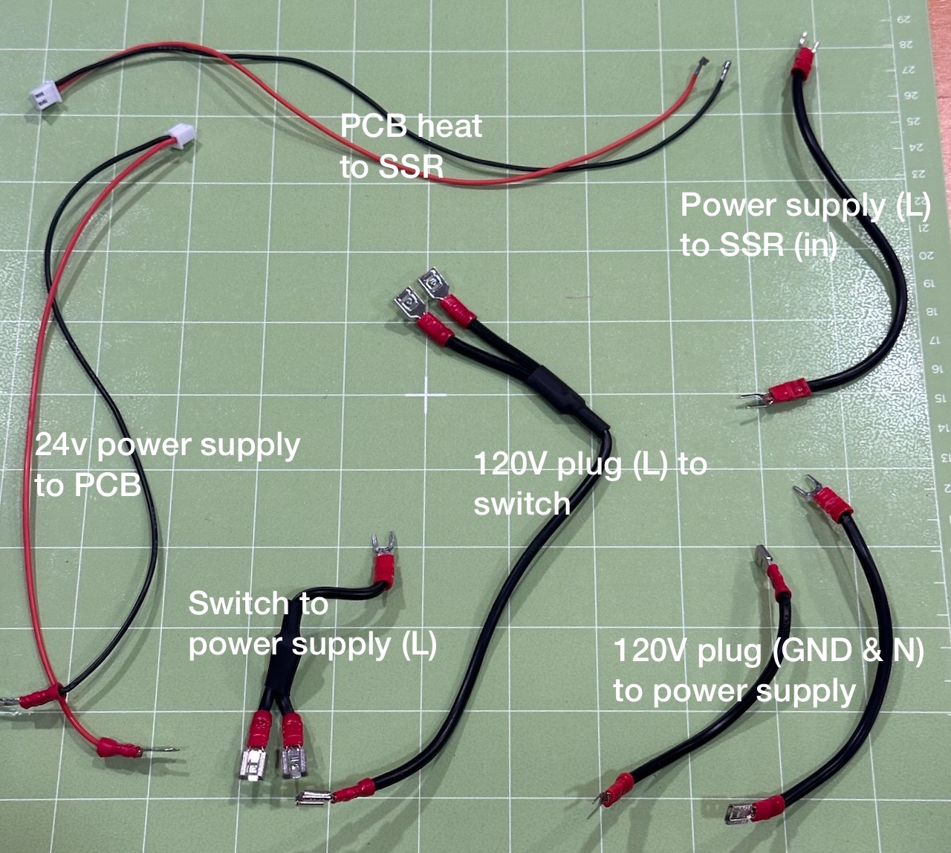
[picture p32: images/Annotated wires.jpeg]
Annotated wiring reference


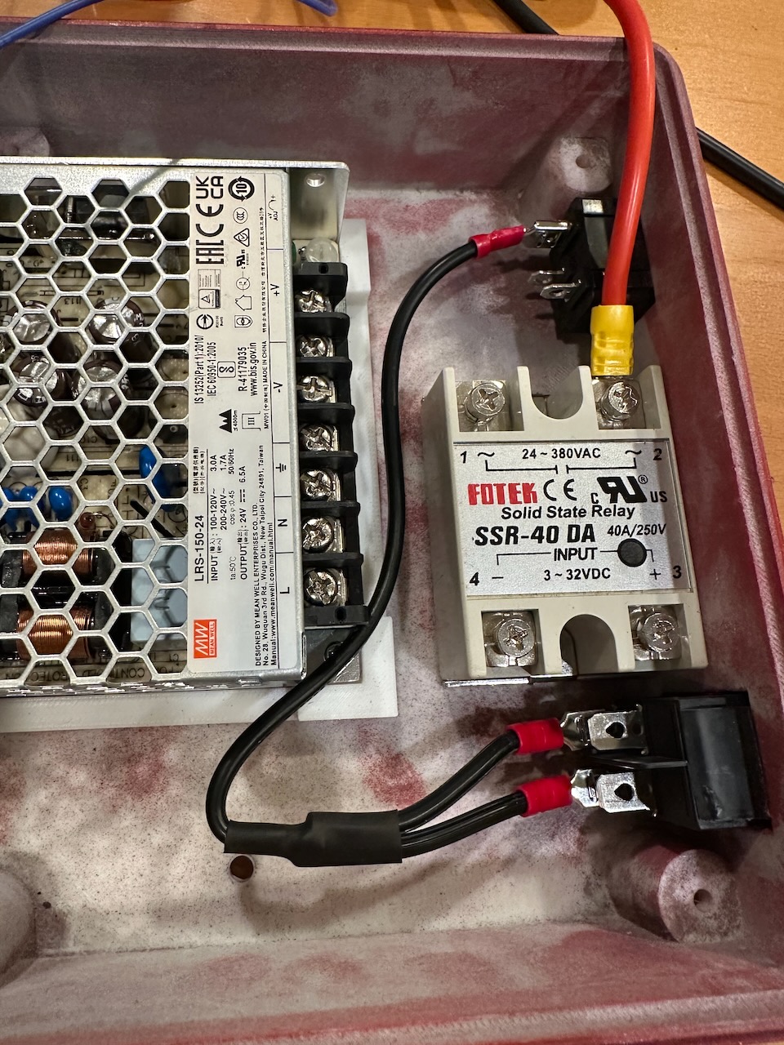
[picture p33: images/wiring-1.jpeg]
Wiring reference 1


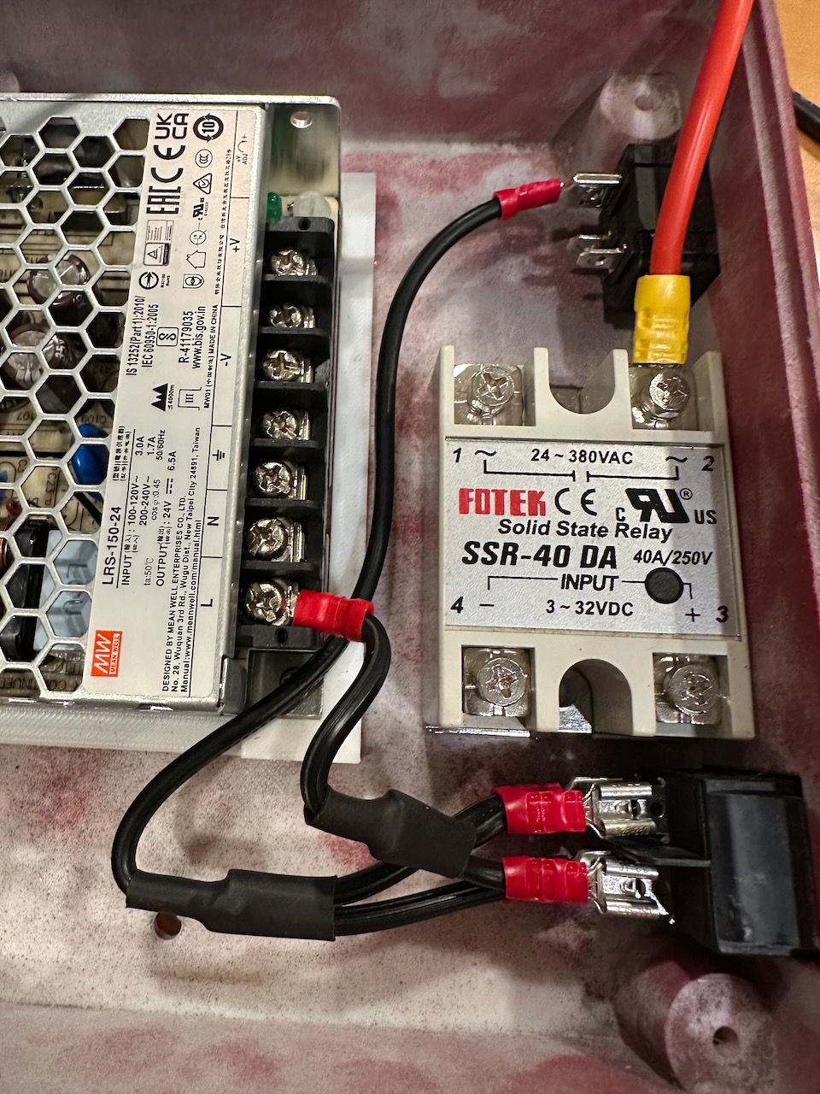
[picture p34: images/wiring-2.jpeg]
Wiring reference 2


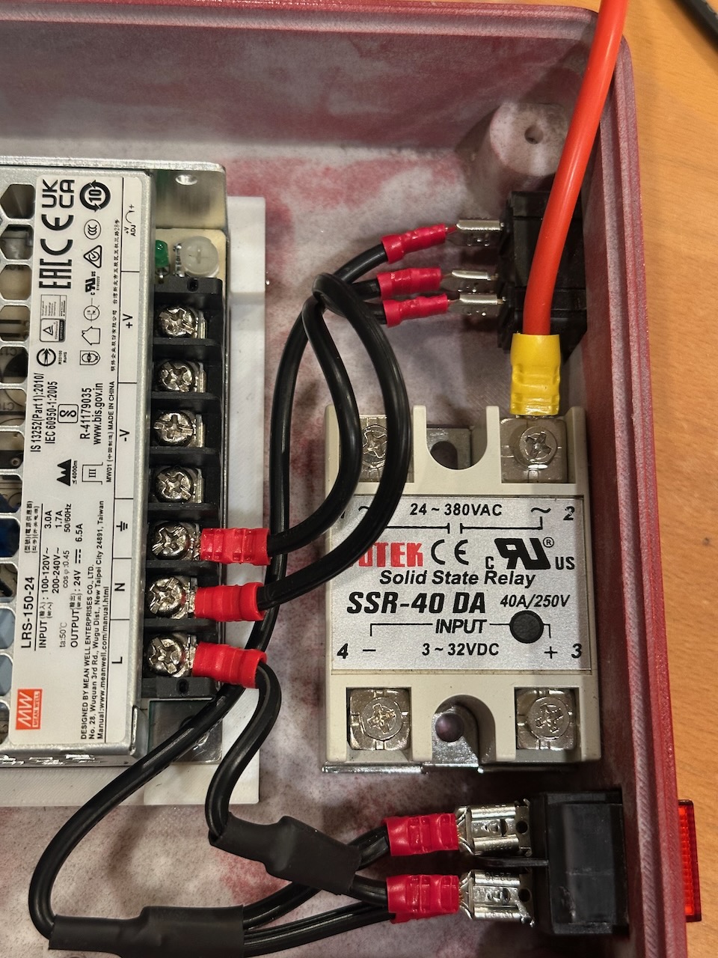
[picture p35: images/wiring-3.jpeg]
Wiring reference 3


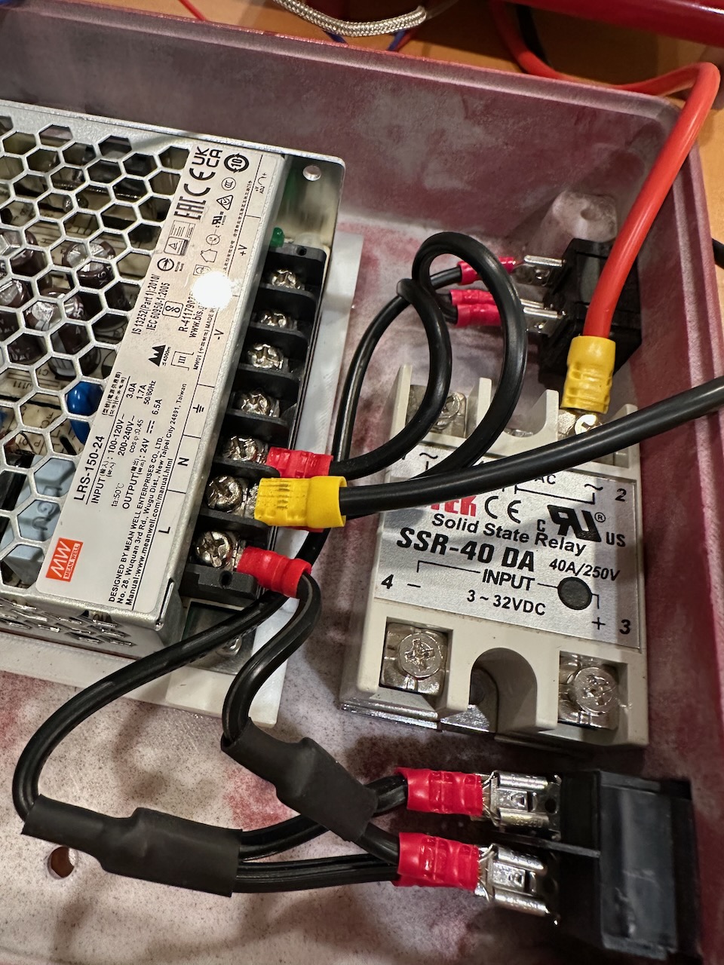
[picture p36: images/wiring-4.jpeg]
Wiring reference 4


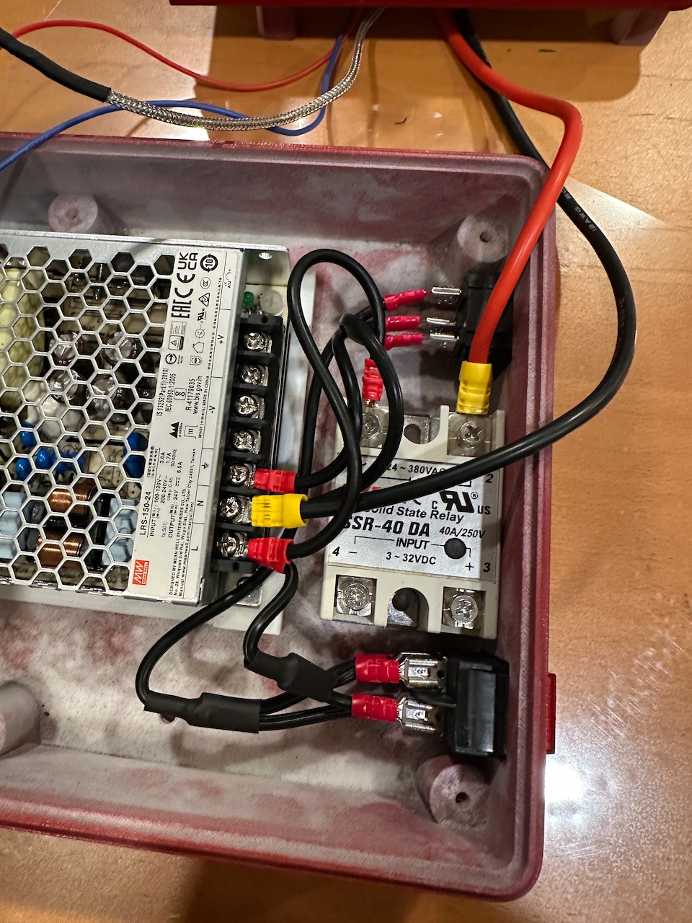
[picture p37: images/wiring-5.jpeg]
Wiring reference 5


Completed wiring reference

Wiring rules:

- Keep mains wiring separate from thermocouple and logic wiring.
- Use heat shrink or insulated splice connectors on every exposed splice.
- Use M3 fasteners as the standard hardware wherever practical.
- Use M4 hardware where needed for the popper base mounting.

Before applying power, verify:

- no exposed mains conductors
- correct heater routing through the SSR
- correct fan wiring for the chosen motor option
- thermocouples connected to the expected bean and exhaust inputs
- low-voltage polarity is correct throughout the controller wiring

## Step 6: Install Firmware

After the hardware is complete:

1. Go to `roaster-firmware/`.
2. Run `./tools/bootstrap.sh` if you have not prepared the environment yet.
3. Build with `./tools/firmware.sh build --board jc4827w543c`.
4. Upload with `./tools/firmware.sh upload --board jc4827w543c` or use OTA if the unit is already provisioned.
5. Open the local UI and web console.

## Step 7: First Power-Up And Validation

Perform the first power-up with the heater disabled or closely supervised.

Check the following before roasting coffee:

- the display boots cleanly
- WiFi setup works
- both temperatures look plausible at room temperature
- heater output changes only when commanded
- fan outputs respond correctly for the chosen motor option
- emergency and error states force the heater off
- cooldown behavior works and can be observed from the UI or web console

Do not start roasting until all of those checks pass.

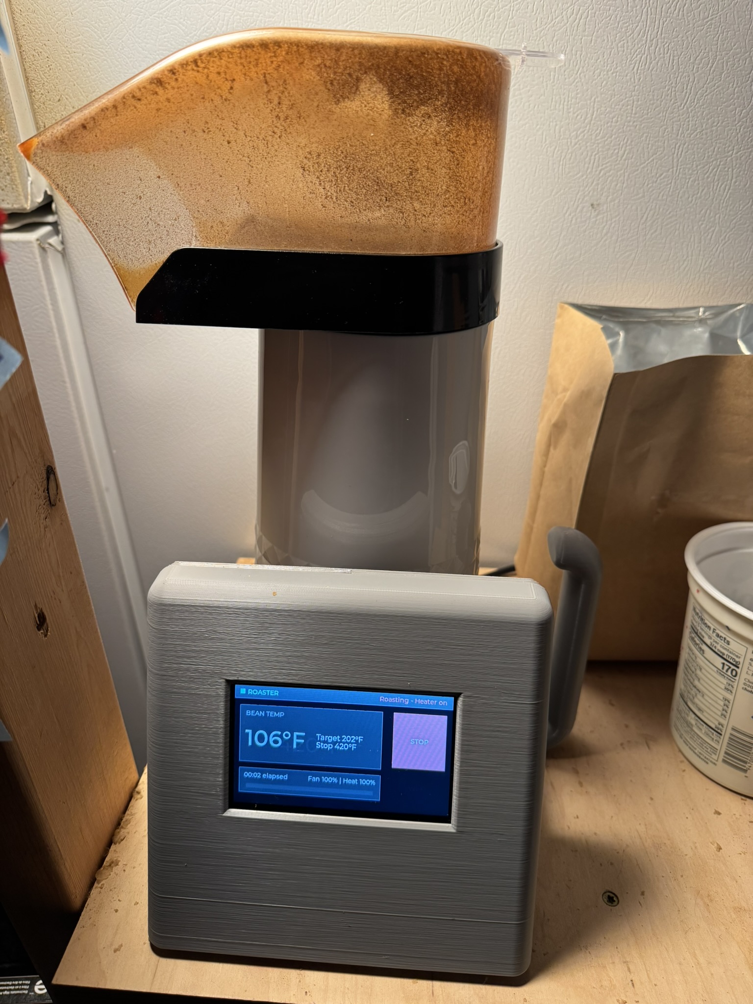
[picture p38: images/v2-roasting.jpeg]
Assembled roaster ready for validation


## Troubleshooting Notes

- If temperatures read erratically, inspect thermocouple routing first and move the probe leads farther away from heater and motor wiring.
- If the switch is difficult to fit, confirm the plastic tabs were removed before gluing it into the enclosure.
- If the fan does not respond as expected, confirm that you wired the correct control hardware for Option A or Option B.

## Related Files

- [BOM.md](BOM.md) for sourcing links and part quantities
- [roaster-firmware/README.md](roaster-firmware/README.md) for firmware workflows

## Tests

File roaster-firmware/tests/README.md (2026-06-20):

# Coffee Roaster Firmware - Test Suite Documentation

## Overview

This directory contains comprehensive unit tests and hardware validation tests for the coffee roaster firmware. The tests are designed to verify correct operation of all major subsystems including profile management, PID control, state machine behavior, and critical safety features.

## Test Organization

```
tests/
├── README.md                    # This file
├── unit_tests.ino               # Main test runner
├── test_profiles.ino            # Profile management tests
├── test_pid.ino                 # PID controller tests
├── test_state_machine.ino       # State machine tests
├── test_safety.ino              # Safety system tests
└── hardware_validation.ino      # Hardware-in-the-loop tests
```

## Prerequisites

### Software Requirements

1. **arduino-cli** - Command line tool for Arduino development
   ```bash
   brew install arduino-cli  # macOS
   ```

2. **ESP32 Platform**
   ```bash
   arduino-cli config add board_manager.additional_urls https://raw.githubusercontent.com/espressif/arduino-esp32/gh-pages/package_esp32_index.json
   arduino-cli core update-index
   arduino-cli core install esp32:esp32
   ```

3. **AUnit Testing Framework**
   ```bash
   arduino-cli lib install "AUnit"
   ```

4. **Project Dependencies**
   ```bash
   arduino-cli lib install "MAX6675 library"
   arduino-cli lib install "SimpleTimer"
   arduino-cli lib install "AutoPID"
   arduino-cli lib install "ESP32Servo"
   ```

### Hardware Requirements (for hardware validation only)

- JC4827W543C ESP32-S3 display board
- Roaster control board with:
  - MAX6675 thermocouple amplifiers (x2)
  - Heating element control circuit
  - PWM fan
  - BDC fan with servo control
  - Appropriate power supply

## Running Unit Tests

Unit tests verify software logic without requiring hardware. They test algorithms, data structures, and control flow.

Canonical test entrypoint:

```bash
cd roaster-firmware
./tools/tests.sh list
./tools/tests.sh compile safety
./tools/tests.sh run pid
```

Legacy compatibility note: `./run_tests.sh` still works and forwards to the new `tools/` entrypoints.

### Running Individual Test Suites

#### Profile Management Tests
```bash
cd roaster-firmware
./tools/tests.sh run profiles --board jc4827w543c
```

Tests covered:
- Adding/clearing setpoints
- Temperature interpolation between setpoints
- Fan speed interpolation
- Profile progress calculation
- Serialization/deserialization
- Boundary conditions

#### PID Controller Tests
```bash
./tools/tests.sh run pid --board jc4827w543c
```

Tests covered:
- Output clamping (0-255 range)
- Response to setpoint changes
- Proportional term behavior
- Integral term accumulation
- Anti-windup protection
- Stability and settling time

#### State Machine Tests
```bash
./tools/tests.sh run state --board jc4827w543c
```

Tests covered:
- State transitions (IDLE → START_ROAST → ROASTING → COOLING → IDLE)
- Safety interlocks (no heater in IDLE/COOLING)
- Emergency stop from any state
- Invalid transition prevention
- Timing and duration tracking

#### Safety System Tests
```bash
./tools/tests.sh run safety --board jc4827w543c
```

Tests covered (CRITICAL):
- Thermal runaway detection
- Over-temperature protection
- Sensor failure detection (open/shorted thermocouple)
- Emergency shutdown procedures
- Fail-safe behavior
- Multiple fault conditions

### Running All Unit Tests

```bash
./tools/tests.sh run unit
```

## Running Hardware Validation Tests

**⚠️ SAFETY WARNING**: Hardware validation tests control real heating elements and fans. 

### Safety Precautions

- [ ] Never leave hardware unattended during testing
- [ ] Have a fire extinguisher nearby
- [ ] Ensure adequate ventilation
- [ ] Keep flammable materials away
- [ ] Monitor temperature readings continuously
- [ ] Be prepared to cut power immediately if needed

### Running Hardware Tests

```bash
./tools/tests.sh run hardware --board jc4827w543c
```

Tests covered:
- Thermocouple reading verification
- Sensor consistency checks
- Heater control (PWM)
- PWM fan control
- BDC fan control (servo)
- Fan cooling effectiveness
- Emergency shutdown verification
- Over-temperature protection
- Short roast cycle simulation

The hardware tests include a 10-second countdown before starting. Press RESET to abort if needed.

## Interpreting Test Results

### Test Output Format

```
Testing: Profile_AddSetpoint_Basic... ✓ PASS
Testing: PID_OutputClamping_MaxValue... ✓ PASS
Testing: Safety_ThermalRunaway_Detection... ✓ PASS
```

### Test Summary

At the end of each test run:
```
═══════════════════════════════════════════════════════════
                     TEST SUMMARY                          
═══════════════════════════════════════════════════════════
Total Tests:   45
Passed:        45 (100%)
Failed:        0
Skipped:       0
═══════════════════════════════════════════════════════════
✓ ALL TESTS PASSED!
```

### Failure Analysis

When a test fails, you'll see:
```
Testing: PID_OutputClamping_MaxValue... ✗ FAIL
  Expected: 255
  Actual:   270
  At line: 87
```

Common failure causes:
- **Timing issues**: Tests may be sensitive to delays
- **Hardware variation**: Component tolerances
- **Environmental factors**: Ambient temperature affects readings
- **Sensor drift**: Thermocouples may need calibration

## Continuous Integration

### GitHub Actions Workflow

The project uses GitHub Actions for automated testing. See `.github/workflows/arduino-ci.yml` for the CI configuration.

Workflow triggers:
- Push to `main`, `add-bdc`, or `develop` branches
- Pull requests to `main`

CI steps:
1. Install arduino-cli
2. Install ESP32 platform
3. Install dependencies
4. Compile firmware
5. Compile all test suites
6. Archive build artifacts

### Local Pre-Commit Testing

Before committing changes, run:

```bash
# Quick compile check
cd roaster-firmware && ./tools/firmware.sh build

# Run unit tests (if you have hardware)
cd roaster-firmware && ./tools/tests.sh compile profiles
```

## Test Coverage

### Current Coverage

| Component | Unit Tests | Hardware Tests | Coverage |
|---|---|---|---|
| Profile Management | ✓ | ✓ | High |
| PID Controller | ✓ | ✓ | High |
| State Machine | ✓ | ✓ | High |
| Safety Systems | ✓ | ✓ | Critical |
| Temperature Sensors | ✓ | ✓ | High |
| Heater Control | ✓ | ✓ | High |
| Fan Control | ✓ | ✓ | High |
| Network/WiFi | ✗ | ✗ | Low |

### Areas for Improvement

- Network communication tests
- WebSocket message handling
- Long-duration roast tests
- Temperature ramp rate tests
- Power cycle/recovery tests

## Adding New Tests

### Creating a New Test

1. Create a new `.ino` file in the `tests/` directory
2. Include AUnit framework:
   ```cpp
   #include <AUnit.h>
   using namespace aunit;
   ```

3. Write test cases:
   ```cpp
   test(YourTest_Description) {
     // Arrange
     int expected = 42;
     
     // Act
     int actual = yourFunction();
     
     // Assert
     assertEqual(expected, actual);
   }
   ```

4. Add setup and loop:
   ```cpp
   void setup() {
     Serial.begin(115200);
     while (!Serial);
   }
   
   void loop() {
     TestRunner::run();
   }
   ```

5. Compile and run:
   ```bash
   ./tools/tests.sh compile your-suite --board jc4827w543c
   ```

### Test Naming Conventions

- Test files: `test_<component>.ino`
- Test functions: `test(<Component>_<Feature>_<Scenario>)`
- Examples:
  - `test(Profile_Interpolation_LinearRamp)`
  - `test(Safety_OverTemp_EmergencyShutdown)`
  - `test(PID_Response_LargeStepChange)`

### AUnit Assertions

Common assertions:
- `assertEqual(expected, actual)` - Values must match
- `assertNotEqual(a, b)` - Values must differ
- `assertTrue(condition)` - Condition must be true
- `assertFalse(condition)` - Condition must be false
- `assertLess(a, b)` - a must be < b
- `assertMore(a, b)` - a must be > b
- `assertNear(expected, actual, tolerance)` - For floating point

## Troubleshooting

### Common Issues

**Problem**: Tests won't compile
- **Solution**: Ensure AUnit library is installed: `arduino-cli lib install "AUnit"`

**Problem**: Upload fails
- **Solution**: Check USB connection, verify correct port: `arduino-cli board list`

**Problem**: Tests hang or timeout
- **Solution**: Increase timeout in test setup: `TestRunner::setTimeout(120)`

**Problem**: Hardware tests exceed temperature limits
- **Solution**: Reduce `MAX_TEST_HEATER_OUTPUT` in `hardware_validation.ino`

**Problem**: Inconsistent sensor readings
- **Solution**: Check thermocouple connections, verify MAX6675 power supply

### Getting Help

- Review main firmware code in `roaster-firmware.ino`
- Check component datasheets (MAX6675, ESP32)
- Review AUnit documentation: https://github.com/bxparks/AUnit
- Check GitHub Issues for known problems

## Best Practices

1. **Run tests frequently** during development
2. **Write tests first** for new features (TDD)
3. **Test safety features** thoroughly and repeatedly
4. **Never skip hardware validation** before deploying to production
5. **Document test failures** and resolutions
6. **Keep tests fast** - unit tests should complete in seconds
7. **Make tests deterministic** - avoid random values
8. **Test boundary conditions** - min/max values, edge cases
9. **Test error conditions** - sensor failures, invalid inputs
10. **Update tests** when changing firmware behavior

## Safety Testing Checklist

Before declaring the firmware production-ready:

- [ ] All unit tests pass
- [ ] All hardware validation tests pass
- [ ] Thermal runaway protection verified
- [ ] Over-temperature protection verified
- [ ] Sensor failure detection verified
- [ ] Emergency stop tested from all states
- [ ] Multiple complete roast cycles tested successfully
- [ ] Cooling cycle tested to completion
- [ ] Power cycle recovery tested
- [ ] Sensor disconnection during roast tested
- [ ] Maximum temperature limits respected
- [ ] Fan failure handling verified

## License

This test suite is part of the coffee roaster firmware project. Refer to the main project README for licensing information.

## Contributing

When contributing new features:
1. Write tests for new functionality
2. Ensure all existing tests still pass
3. Add hardware validation if applicable
4. Update this README with new test coverage
5. Submit PR with test results

---

**Remember**: This device controls high temperatures and line voltage. All code changes must pass safety tests. Never deploy untested code to hardware that will roast coffee unattended.

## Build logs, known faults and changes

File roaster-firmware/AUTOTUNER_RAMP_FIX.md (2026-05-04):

# Fix: Autotuned PID Lags 10–20°F Behind Ramp Setpoint

## Diagnosis

### Observed Behavior

The step-response autotuner produces Kp=1.077, Ki=0.031, Kd=7.64 with τ_c factor 0.5.
During a roast with ~0.5°F/s ramp rate, the actual temperature consistently lags
10–20°F behind the setpoint.

### Root Cause 1: FOPDT Dead Time is Grossly Overestimated

The SIMC steady-state ramp tracking error for a PI controller on a FOPDT plant is
**exactly**:

$$e_{ss} = R \times (\tau_c + \theta)$$

where $R$ is the ramp rate (°F/s).

With the calibration results (Band 2):
- θ_model = 21.28s (from S-K / least-squares fit)
- τ_c = 0.5 × 21.28 = 10.64s
- Ramp rate ≈ 0.5°F/s

$$e_{ss} = 0.5 \times (10.64 + 21.28) = \textbf{16.0°F}$$

This matches the observed lag perfectly.

**But the 21s dead time is wrong.** Looking at the Band 2 step response data, the
temperature begins rising within 3–5 seconds of the step input:

| Time (s) | Temp (°F) | ΔT from baseline |
|---|---|---|
| 0 | 232.1 | 0.0 |
| 3 | 232.7 | +0.6 (noise) |
| 5.75 | 234.1 | +2.0 (real) |
| 10 | 234.5 | +2.4 |
| 20 | 240.0 | +7.9 |

The noise floor during stabilization is σ ≈ 0.4°F (samples oscillate ±0.5°F).
The temperature first exceeds baseline + 3σ ≈ 233.3°F at about **t = 5s**.

The true transport delay (thermocouple thermal mass + air transit) is ~3–5 seconds.
The FOPDT model reports θ = 21s because the Sundaresan-Krishnaswamy and least-squares
methods lump the system's **multiple thermal time constants** (heater → drum → air →
thermocouple) into a single first-order + dead time approximation. Since the real
system is higher order than FOPDT, the fit compensates by inflating θ.

This is a well-known limitation of FOPDT modeling for higher-order thermal systems
(see Skogestad & Grimholt 2012, §5.3.2: "For processes with several time constants,
the FOPDT approximation gives too large a delay").

### Root Cause 2: PIDRuntimeController Feedforward is Broken

The `PIDRuntimeController` computes ramp feedforward as:

```cpp
double rawFeedforward = (desiredRate - band.drift - band.coolingCoeff * (...)) 
                        / max(band.heaterCoeff, 1e-6);
```

The step-response tuner's `getCharacterizationSummary()` **never populates**
`drift`, `coolingCoeff`, or `heaterCoeff` in `BandCharacterization` — they're
all left at 0.0. This causes:

- `heaterCoeff = 0` → denominator becomes `1e-6`
- `rawFeedforward = desiredRate / 1e-6` → ~500,000
- After `constrain(..., 0, 255)` → feedforward saturates at **255 always**
- Total output = `clamp(PID + 255, 0, 255)` = **heater stuck at max**

The PID then fights against a full-on heater by driving its integral term
negative. The result is erratic output and poor tracking.

> **Note:** The sawtooth tuner has the same bug — it also never sets these
> three fields. The bug was latent because the sawtooth tuner rarely produces
> 2+ valid bands needed to enable the scheduler.

### Combined Effect

With broken feedforward AND inflated dead time, the autotuned controller has:
- PID gains that are 4× too conservative (Kc = 1.08 vs. needed ~4.0)
- A feedforward term that either does nothing (schedule off) or saturates at max

## Proposed Fix: Three Changes

### Change 1: Response Onset Dead Time Detector

Add a direct measurement of when the temperature first responds to the step input,
and use this shorter value for SIMC gain computation.

**Algorithm:**

During the STABILIZE phase, compute the noise standard deviation σ from the last
120 samples (30 seconds at 250ms intervals). During the RECORD phase, detect when
T(t) first exceeds T_baseline + k×σ (where k = 3 for 99.7% confidence).

```
θ_onset = time when T first exceeds baseline + 3σ
θ_onset = max(θ_onset, 1.0)  // always at least 1 second
```

Use `θ_onset` for SIMC gain computation instead of the FOPDT-fitted θ:

```
τ_c = configTauCFactor × θ_onset
Kc = τ / (Kp × (τ_c + θ_onset))
τ_I = min(τ, 4 × (τ_c + θ_onset))
τ_D = θ_onset / 3
```

Keep the FOPDT-fitted `θ_model` for logging, display, and feedforward lead time.

**Expected gains with θ_onset ≈ 5s:**
- τ_c = 0.5 × 5 = 2.5s
- Kc = 34.5 / (1.0 × 7.5) = **4.60** (vs. current 1.08)
- Ki = 4.60 / 34.5 = **0.133** (vs. current 0.031)
- Kd = 4.60 × 5/3 = **7.67** (similar)
- Ramp error: 0.5 × 7.5 = **3.75°F** (vs. current 16°F)

**Implementation in `StepResponseTuner.hpp`:**

1. Add `double noiseStdDev` to the class state, computed during STABILIZE from the
   last 120 samples' standard deviation.

2. Add `double onsetDeadTime` to `FOPDTModel` and `BandResult`.

3. During RECORD phase, find the first sample where `T > baselineTemp + 3 × noiseStdDev`.
   Store the time as `onsetDeadTime`.

4. In `computeSIMC()`, use `max(onsetDeadTime, 1.0)` for θ in the SIMC formulas.
   Use the FOPDT-fitted `deadTime` for the derivative term if larger (conservative D).

### Change 2: Populate Feedforward Model Fields

The step-response FOPDT model provides exactly the parameters needed for
`PIDRuntimeController` feedforward. Add mappings in `getCharacterizationSummary()`:

```cpp
// FOPDT process gain = ΔT / Δu (°F per PWM count)
// heaterCoeff in the feedforward formula = dT/dt per unit heater output
// For a FOPDT model: heaterCoeff ≈ processGain / timeConstant
bc.heaterCoeff = br.model.processGain / max(br.model.timeConstant, 1.0);

// coolingCoeff: approximate from steady-state energy balance
// At baseline: heaterCoeff * u_baseline = coolingCoeff * (T_baseline - T_ambient)
// So: coolingCoeff = heaterCoeff * u_baseline / (T_baseline - T_ambient)
double tempDiff = br.model.baselineTemp - ambientTemp;
if (tempDiff > 10.0) {
    bc.coolingCoeff = bc.heaterCoeff * br.model.baselineOutput / tempDiff;
} else {
    bc.coolingCoeff = 0.0;
}

// drift: should be ~0 at steady state, but include for completeness
bc.drift = 0.0;
```

This enables the `PIDRuntimeController` feedforward to compute physically
meaningful values instead of dividing by 1e-6.

**With correct heaterCoeff** (≈ 1.0/34.5 ≈ 0.029 °F/s per PWM count):

```
// At 0.5°F/s ramp rate:
rawFeedforward = (0.5 - 0 - coolingCorrection) / 0.029 ≈ 17 PWM
```

This is a sensible feedforward value that pre-loads the heater output
proportionally to the ramp rate.

### Change 3: Use θ_model for Feedforward Lead Term

The `PIDRuntimeController` already has a setpoint lead feature:

```cpp
double leadTarget = setpointTemp + desiredRate * min(band.deadTime, 12.0);
```

With the correctly populated `deadTime` from the FOPDT model (21s, capped at 12s),
this advances the setpoint by up to 12 × 0.5 = 6°F, helping the feedforward
anticipate the ramp. This is a simple form of dead-time compensation.

Currently this works because `deadTime` IS populated from the FOPDT model. After
Change 2 populates `heaterCoeff`, the feedforward will compute meaningful values
and this lead term will properly reduce ramp lag.

## Expected Outcome

| Metric | Current | After Fix |
|---|---|---|
| SIMC θ used | 21.3s (FOPDT fit) | ~5s (onset measured) |
| Kc (proportional) | 1.08 | ~4.6 |
| Ki (integral) | 0.031 | ~0.133 |
| Ramp error (PID only) | 16°F | ~3.8°F |
| Feedforward | Broken (0 or 255) | ~17 PWM at 0.5°F/s |
| Ramp error (PID + FF) | 16°F | **~1–2°F** |

## Safety Considerations

- Higher Kc increases the risk of oscillation if the onset dead time underestimates
  the true effective delay. Mitigate by clamping θ_onset ≥ 1.0s and monitoring Ms
  (sensitivity peak). The SIMC rules with τ_c = 0.5θ give Ms ≈ 1.8–2.0, which is
  acceptable for this thermal system.

- The feedforward is already constrained to [0, 255] and filtered (α = 0.35 EMA).
  Correct heaterCoeff values will produce moderate feedforward (10–30 PWM) instead
  of the current saturated 255.

- The heater output sum `PID + feedforward` is already clamped to [0, 255].
  No additional safety measures needed.

## Implementation Scope

| File | Change |
|---|---|
| `StepResponseTuner.hpp` | Add noise σ computation in STABILIZE, onset detector in RECORD, `onsetDeadTime` field in FOPDTModel, use onset θ in `computeSIMC()` |
| `StepResponseTuner.hpp` | Populate `drift`, `coolingCoeff`, `heaterCoeff` in `getCharacterizationSummary()` |
| `PIDAutotuner.hpp` | Same feedforward field fix in sawtooth `getSummary()` (populate from model) |
| Tests | Update `test_step_response.ino` expected PID gains for onset-based θ |

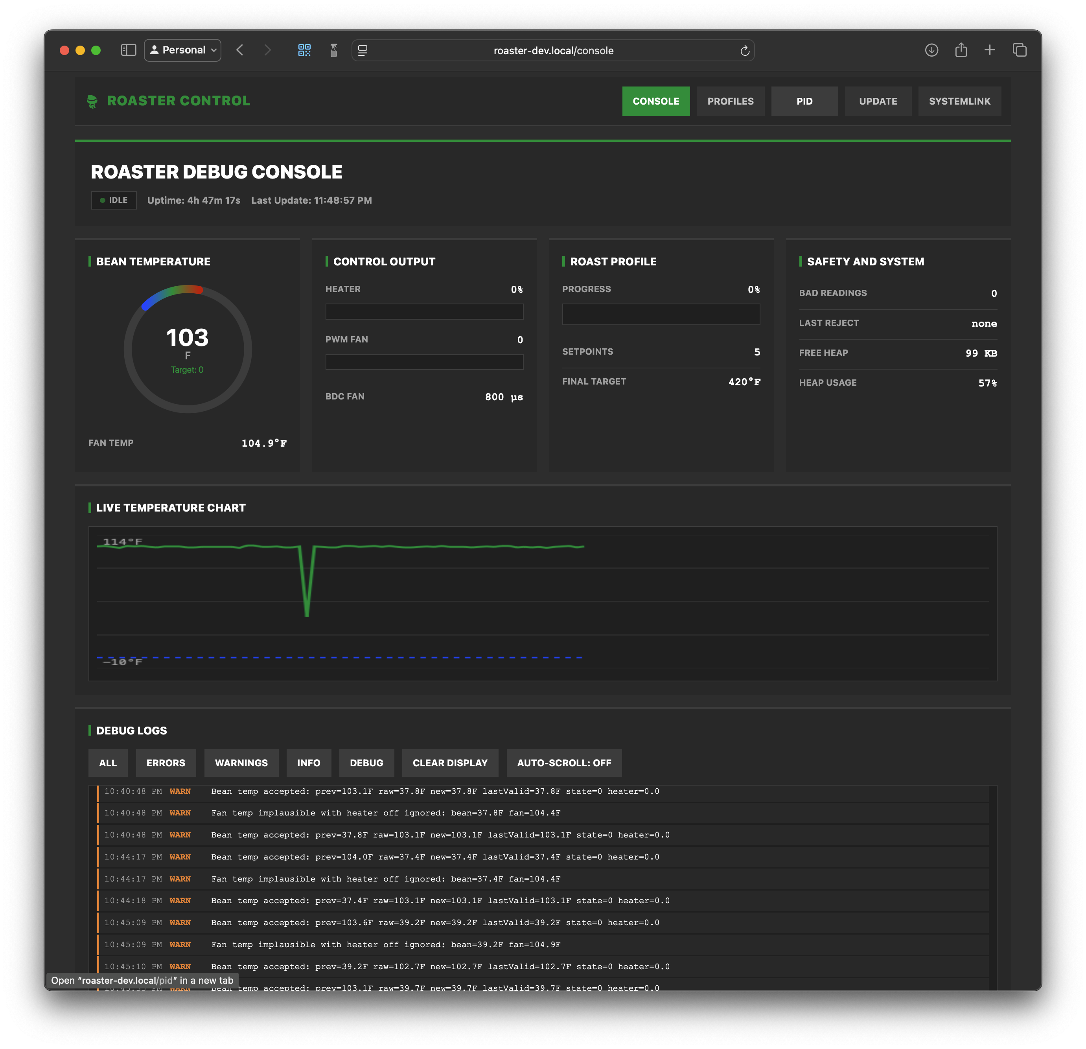
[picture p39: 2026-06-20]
images/debug-console.png

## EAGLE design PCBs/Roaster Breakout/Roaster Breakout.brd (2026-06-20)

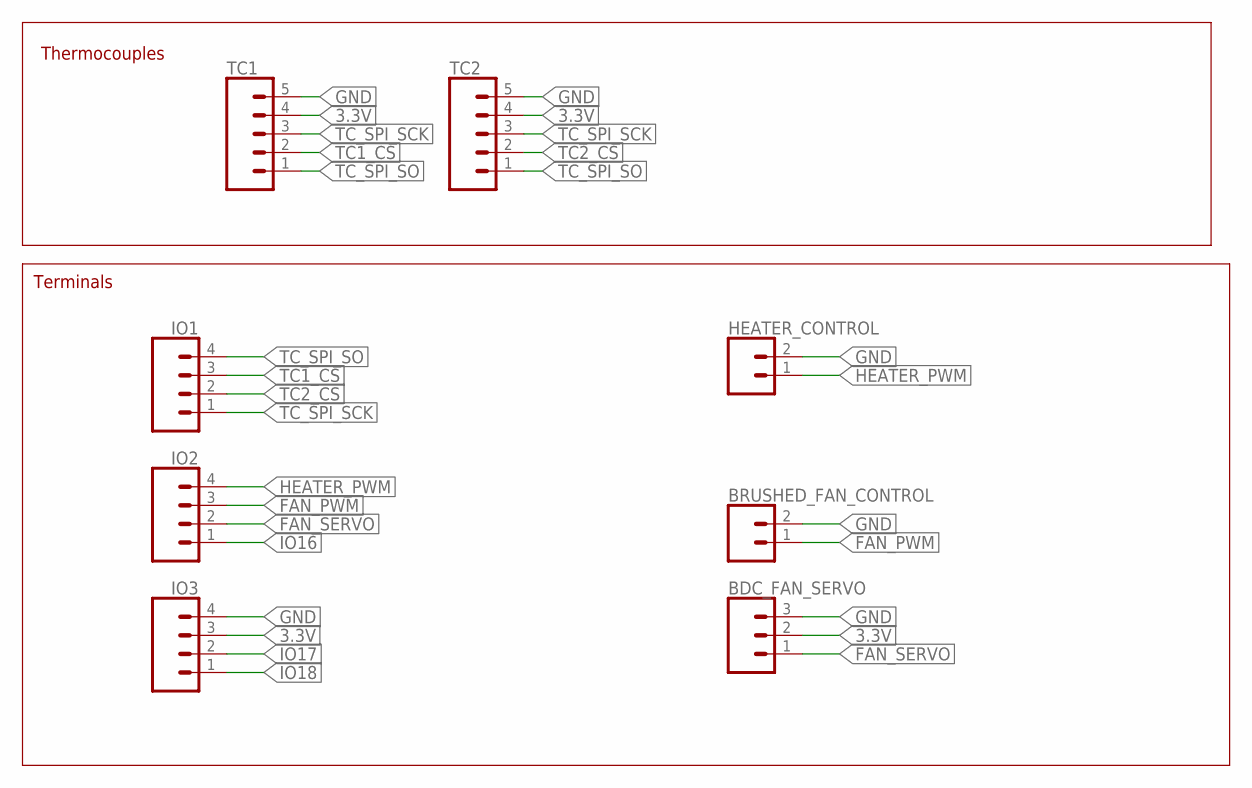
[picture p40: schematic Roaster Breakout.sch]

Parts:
BDC_FAN_SERVO: CONN_03LONGPADS; 1X03_LONGPADS
BRUSHED_FAN_CONTROL: CONN_02PTH3; 1X02_LONGPADS
HEATER_CONTROL: CONN_02PTH3; 1X02_LONGPADS
IO1, IO2, IO3: CONN_04LONGPADS; 1X04_LONGPADS
TC1, TC2: CONN_05PTH_LONGPADS; 1X05_LONGPADS

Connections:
3.3V: BDC_FAN_SERVO.2, IO3.3, TC1.4, TC2.4
FAN_PWM: BRUSHED_FAN_CONTROL.1, IO2.3
FAN_SERVO: BDC_FAN_SERVO.1, IO2.2
GND: BDC_FAN_SERVO.3, BRUSHED_FAN_CONTROL.2, HEATER_CONTROL.2, IO3.4, TC1.5, TC2.5
HEATER_PWM: HEATER_CONTROL.1, IO2.4
IO16: IO2.1
IO17: IO3.2
IO18: IO3.1
TC1_CS: IO1.3, TC1.2
TC2_CS: IO1.2, TC2.2
TC_SPI_SCK: IO1.1, TC1.3, TC2.3
TC_SPI_SO: IO1.4, TC1.1, TC2.1

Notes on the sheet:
Thermocouples
Terminals

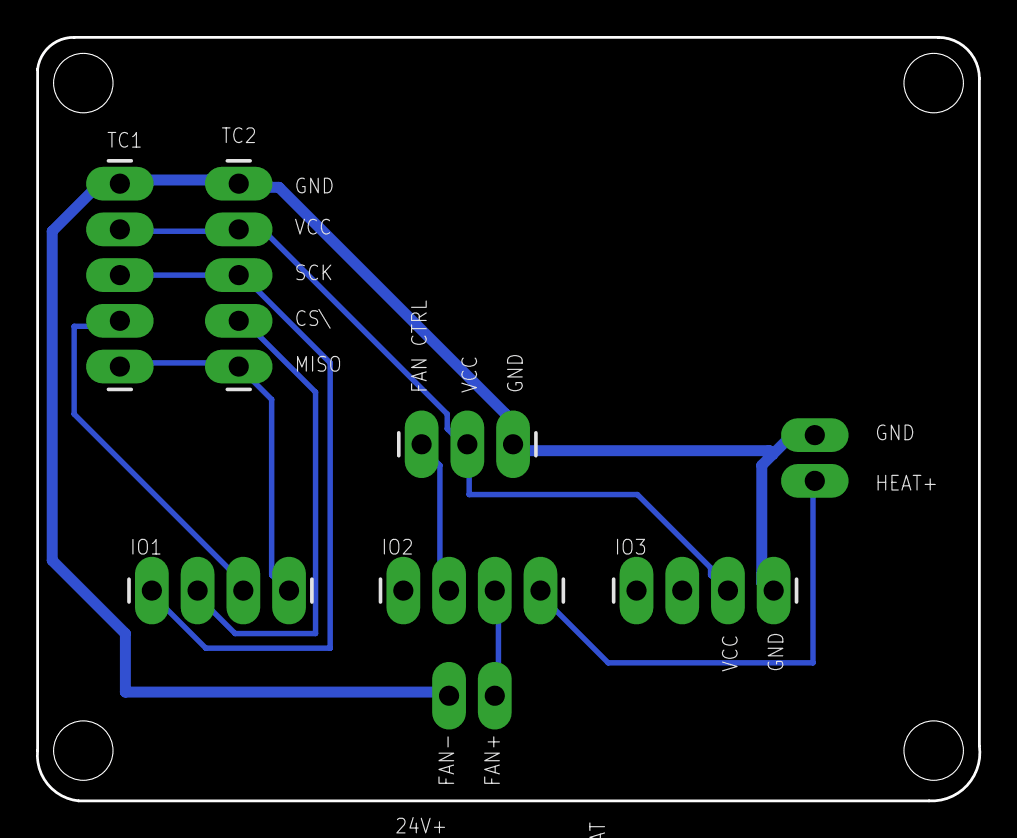
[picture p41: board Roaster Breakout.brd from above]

Board: 2 copper layers, 52.4 x 42.4 mm, 9 parts (0 on the bottom side), 9 nets.

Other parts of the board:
U$1: LOGO

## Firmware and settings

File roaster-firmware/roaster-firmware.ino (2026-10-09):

#include "Arduino.h"
#include <max6675.h>
#include <SimpleTimer.h>
#include <PWMrelay.h>
#include <SPI.h>
#include <Preferences.h>
#include <ElegantOTA.h> // v3.1.7+ with async mode enabled for ESPAsyncWebServer compatibility
#include <ESP32Servo.h>
#include <esp_heap_caps.h>
#include <esp_task_wdt.h> // Hardware watchdog timer

// Debug macros (must be defined before including src/network/Network.hpp)
#define DEBUG

#ifdef DEBUG
#define DEBUG_SERIALBEGIN(x) Serial.begin(x)
#define DEBUG_PRINT(x) Serial.print(x)
#define DEBUG_PRINTLN(x) Serial.println(x)
#define DEBUG_PRINTF(...) Serial.printf(__VA_ARGS__)

#else
#define DEBUG_SERIALBEGIN(x) // blank line
#define DEBUG_PRINT(x)       // blank line
#define DEBUG_PRINTLN(x)     // blank line
#define DEBUG_PRINTF(...)    // blank line
#endif

#include "src/platform/RoasterTypes.hpp"
#include "src/platform/BoardConfig.hpp"
#include "src/display/DisplayBackendConfig.hpp"
#include "src/support/DebugLog.hpp"
#include "src/display/DisplayAdapter.hpp"
#include "src/display/DisplayActionRouter.hpp"
#include "src/control/PIDController.hpp"
#include "src/profiles/RoastProfile.hpp"
#include "src/profiles/ProfileManager.hpp"
#include "src/profiles/ProfileEditor.hpp"
#include "src/control/StepResponseTuner.hpp"
#include "src/control/PIDRuntimeController.hpp"
#include "src/control/PIDValidation.hpp"
#include "src/control/RoastControlLoop.hpp"
#include "src/control/RoastSessionLifecycle.hpp"
#include "src/integrations/SystemLink.hpp"

extern char activeFaultCode[32];
extern char activeFaultMessage[96];
bool canClearErrorState();

#include "src/network/Network.hpp"

Preferences preferences;

// Pin definitions
constexpr int TC1_CS = BoardConfig::BeanThermocoupleChipSelectPin;
constexpr int TC2_CS = BoardConfig::FanThermocoupleChipSelectPin;
constexpr int THERMOCOUPLE_SCK = BoardConfig::ThermocoupleClockPin;
constexpr int THERMOCOUPLE_MISO = BoardConfig::ThermocoupleDataPin;
constexpr int HEATER = BoardConfig::HeaterPwmPin;
constexpr int FAN = BoardConfig::FanPwmPin;
constexpr int BDCFAN = BoardConfig::BdcFanServoPin;

// PID settings and gains
double kp = 8.0;
double ki = 0.46;
double kd = 0;

// Preferences namespace
#define PREFS_NAMESPACE "roaster"

#ifndef VERSION
#define VERSION "2025-12-24"
#endif

// Use timers for simple multitasking
SimpleTimer checkTempTimer(125);
SimpleTimer tickTimer(5);
SimpleTimer controlLoopTimer(250);
SimpleTimer stateMachineTimer(500);
SimpleTimer wsBroadcastTimer(1000);  // WebSocket broadcast every 1 second
SimpleTimer roastTraceTimer(1000);   // Roast trace capture every 1 second

// PWM is used to control fan and heater outputs
PWMrelay heaterRelay(HEATER, HIGH);
PWMrelay fanRelay(FAN, HIGH);

Servo bdcFan;

static void configureJcHeapForPsram() {
#if ROASTER_TARGET_BOARD == ROASTER_BOARD_JC4827W543C
  if (!psramFound()) {
    LOG_WARN("PSRAM not detected; leaving default heap allocation policy in place");
    return;
  }

  // Prefer PSRAM for general allocations so internal DRAM remains available for TLS.
  heap_caps_malloc_extmem_enable(0);
  LOG_INFO("Configured heap allocator to prefer PSRAM for general allocations");
#endif
}

// Create a roast profile object
RoastProfile profile;
ProfileManager profileManager;

// Roaster state variables
// NOTE: All temperature values throughout this codebase are in Fahrenheit (°F)
double currentTemp = 0;     // Current bean temperature (°F)
double setpointTemp = 0;    // Target temperature from profile (°F)
double heaterOutputVal = 0; // Final heater command (0-255)
double heaterPidTrimVal = 0;
double heaterFeedforwardVal = 0;
byte setpointFanSpeed = 0;  // Target fan speed (0-255)
int setpointProgress = 0;   // Roast time in seconds
int bdcFanMs = 800;         // BDC fan servo pulse width (800-2000 µs)
double fanTemp = 0;         // Inlet/fan temperature sensor (°F)
int badReadingCount = 0;    // Track consecutive bad thermocouple readings
char lastRejectedBeanReadReason[16] = "none";
char activeFaultCode[32] = "none";
char activeFaultMessage[96] = "";

// Restart handling
bool restartRequested = false;
unsigned long restartAt = 0;

// Fan ramp state variables (for non-blocking START_ROAST)
unsigned long fanRampStartTime = 0;
int fanRampStep = 0;

// Cooling state variables
unsigned long coolingStartTime = 0; // Track cooling duration

// WiFi credentials (loaded from preferences in setup())
WifiCredentials wifiCredentials;

// Roaster state variable (enum defined in RoasterTypes.hpp)
RoasterState roasterState = IDLE;

inline bool shouldFilterBeanTempSpikes()
{
  return roasterState == START_ROAST || roasterState == ROASTING || roasterState == COOLING;
}

inline bool shouldFilterFanTempSpikes()
{
  return roasterState == START_ROAST || roasterState == ROASTING || roasterState == COOLING;
}

inline bool shouldEnforceFanTempSafety()
{
  if (roasterState == COOLING) {
    return true;
  }

  if (roasterState != ROASTING) {
    return false;
  }

  // During the roast start transition the heater is still off and the exhaust
  // sensor should remain near ambient. Treat large fan-sensor excursions during
  // that phase as implausible until heating has actually begun.
  if (heaterOutputVal <= 0.0 && currentTemp < 140.0) {
    return false;
  }

  if (roastStartedAtMs == 0) {
    return false;
  }

  if (millis() - roastStartedAtMs < FAN_TEMP_SAFETY_ARM_DELAY_MS) {
    return false;
  }

  return true;
}

inline void setLastRejectedBeanReadReason(const char *reason)
{
  strlcpy(lastRejectedBeanReadReason, reason ? reason : "unknown", sizeof(lastRejectedBeanReadReason));
}

inline bool isRoastActiveState()
{
  return roasterState == START_ROAST || roasterState == ROASTING;
}

inline void setActiveFault(const char *faultCode, const char *displayMessage)
{
  strlcpy(activeFaultCode, faultCode ? faultCode : "unknown_fault", sizeof(activeFaultCode));
  strlcpy(activeFaultMessage, displayMessage ? displayMessage : "Controller fault detected.", sizeof(activeFaultMessage));
}

inline String formatBeanSensorFaultMessage(double reading)
{
  char buffer[96];
  const char *reason = strcmp(lastRejectedBeanReadReason, "spike") == 0 ? "unstable" : "range error";
  snprintf(buffer, sizeof(buffer), "Bean sensor %s (raw %.1fF)", reason, reading);
  return String(buffer);
}

inline bool canClearErrorState()
{
  return badReadingCount == 0 && currentTemp < COOLING_TARGET_TEMP && fanTemp < MAX_SAFE_FAN_TEMP;
}

inline String formatErrorRecoveryBlockedMessage()
{
  if (badReadingCount > 0)
  {
    return String("Sensor fault still active. Fix wiring or sensor signal first.");
  }

  if (currentTemp >= COOLING_TARGET_TEMP)
  {
    char buffer[96];
    snprintf(buffer, sizeof(buffer), "Bean temp %.1fF is still above the 140F safe-idle limit.", currentTemp);
    return String(buffer);
  }

  if (fanTemp >= MAX_SAFE_FAN_TEMP)
  {
    char buffer[96];
    snprintf(buffer, sizeof(buffer), "Fan temp %.1fF is still above the %.0fF safety limit.", fanTemp, MAX_SAFE_FAN_TEMP);
    return String(buffer);
  }

  return String("Fault lockout remains active until the controller reports a safe state.");
}

inline void clearEmergencyErrorState()
{
  LOG_INFOF("Clearing error state: fault=%s bean=%.1fF fan=%.1fF", activeFaultCode, currentTemp, fanTemp);

  roasterState = IDLE;
  coolingStartTime = 0;
  roastStartedAtMs = 0;
  setpointTemp = 0;
  setpointFanSpeed = 0;
  heaterOutputVal = 0;
  heaterPidTrimVal = 0;
  heaterFeedforwardVal = 0;
  badReadingCount = 0;
  setActiveFault("none", "");

  digitalWrite(HEATER, LOW);
  resetRoastControllerState();
  heaterRelay.setPWM(0);
  fanRelay.setPWM(0);
  bdcFan.writeMicroseconds(800);
  bdcFanMs = 800;

  systemLinkUpdateLastFault("none");
  displayShowScreen(DisplayScreen::Start);
}

inline void enterEmergencyErrorState(const char *faultCode, const char *displayMessage)
{
  setActiveFault(faultCode, displayMessage);
  roasterState = ERROR;
  digitalWrite(HEATER, LOW);
  resetRoastControllerState();
  heaterRelay.setPWM(0);
  fanRelay.setPWM(255);
  bdcFan.writeMicroseconds(2000);
  bdcFanMs = 2000;
  systemLinkUpdateLastFault(faultCode);
  systemLinkFinishRoast(SYSTEMLINK_OUTCOME_ERRORED, faultCode);
  displayShowErrorMessage(activeFaultMessage);
}

MAX6675 thermocouple(THERMOCOUPLE_SCK, TC1_CS, THERMOCOUPLE_MISO);
MAX6675 thermocoupleFan(THERMOCOUPLE_SCK, TC2_CS, THERMOCOUPLE_MISO);
PIDController heaterPID(&currentTemp, &setpointTemp, &heaterPidTrimVal, 0, 255, kp, ki, kd);
StepResponseTuner stepTuner;
bool autoValidateAfterCooling = false;
PIDRuntimeController pidRuntimeController;
PIDValidationSession pidValidation;

uint8_t profileBuffer[200];
int finalTempOverride = -1; // UI override for final target temp (F)
RoastProfile validationSavedProfile;
bool validationProfileLoaded = false;
int savedValidationFinalTempOverride = -1;
unsigned long roastStartedAtMs = 0;
double appliedKp = kp;
double appliedKi = ki;
double appliedKd = kd;
bool pidScheduleConfigured = false;
bool pidScheduleActive = false;
int activePidBandIndex = -1;

// Helper function for reliable final-target reads from the active display.
int readDisplayFinalTargetTempWithRetry(int retries = 2)
{
  for (int i = 0; i < retries; i++)
  {
    int value = displayReadFinalTargetTemp();
    if (value != DISPLAY_READ_ERROR)
    {
      return value;
    }
    delay(10); // Small delay before retry
  }
  LOG_WARN("Display final target read failed");
  return DISPLAY_READ_ERROR;
}

uint32_t getEffectiveFinalTargetTemp()
{
  // Use the UI override if set; otherwise fall back to the profile final target.
  if (finalTempOverride > 0)
  {
    return constrain(finalTempOverride, 0, 500);
  }
  return profile.getFinalTargetTemp();
}

void updateCalibrationControl(unsigned long now)
{
  if (roasterState != CALIBRATING || fanRampStep < 2000)
  {
    return;
  }

  updateStepResponseCalibration(now);
}

void updateStepResponseCalibration(unsigned long now)
{
  heaterOutputVal = stepTuner.getOutput(currentTemp, fanTemp, setpointFanSpeed);
  setpointTemp = stepTuner.getSetpoint();
  heaterPidTrimVal = heaterOutputVal;
  heaterFeedforwardVal = 0.0;

  int requestedFanPwm = stepTuner.isRecoveryCooling() ? 255 : setpointFanSpeed;
  fanRelay.setPWM(requestedFanPwm);
  int calibrationBdcValue = stepTuner.isRecoveryCooling() ? 2000 : constrain(5 * requestedFanPwm + 700, 800, 2000);
  bdcFan.writeMicroseconds(calibrationBdcValue);
  bdcFanMs = calibrationBdcValue;
  heaterRelay.setPWM(heaterOutputVal);

  if (stepTuner.isComplete())
  {
    double newKp, newKi, newKd;
    stepTuner.getPID(newKp, newKi, newKd);

    setManualPIDGains(newKp, newKi, newKd);
    pidRuntimeController.clearPreferences(preferences);
    pidScheduleConfigured = false;
    activePidBandIndex = -1;

    // Load per-band models into runtime controller
    Calibration::CharacterizationSummary cs = stepTuner.getCharacterizationSummary();
    pidRuntimeController.loadFromSummary(cs);
    if (pidRuntimeController.isEnabled()) {
      pidRuntimeController.saveToPreferences(preferences);
      pidScheduleConfigured = true;
      LOG_INFO("Step-response band models loaded into gain scheduler");
    }

    LOG_INFOF("Step-response tuning saved: Kp=%.4f, Ki=%.6f, Kd=%.4f", kp, ki, kd);

    // Publish calibration data to SystemLink
    systemLinkPublishCalibration(stepTuner);

    resetRoastControllerState();
    heaterRelay.setPWM(0);
    autoValidateAfterCooling = true;
    enterCoolingState();
    sendWsMessage("{ \"pushMessage\": \"pidTuningComplete\" }");
    return;
  }

  if (!stepTuner.isRunning())
  {
    LOG_WARNF("Step-response tuning ended: %s", stepTuner.getLastError());
    resetRoastControllerState();
    heaterRelay.setPWM(0);
    enterCoolingState();
    if (strcmp(stepTuner.getLastError(), "cancelled") == 0)
    {
      sendWsMessage("{ \"pushMessage\": \"pidTuningCancelled\" }");
    }
    else
    {
      sendWsMessage("{ \"pushMessage\": \"pidTuningFailed\" }");
    }
  }
}
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
void loop()
{
  // Reset watchdog timer every loop iteration
  // If loop hangs for >10 seconds, system will reset
  esp_task_wdt_reset();

  // Reset boot count if system has been stable for 10 seconds
  static bool bootCountReset = false;
  if (!bootCountReset && millis() > 10000) {
    preferences.putInt("boot_count", 0);
    bootCountReset = true;
    LOG_INFO("System stable - boot count reset");
  }

  // Check WiFi connection and auto-reconnect if needed
  checkWiFiConnection(wifiCredentials);

  if (tickTimer.isReady())
  {
    if (!otaUpdateInProgress)
    {
      displayTick();
      handleDisplayActions();
    }
    heaterRelay.tick();
    fanRelay.tick();
    if (!otaUpdateInProgress)
    {
      wsCleanup();
    }
    ElegantOTA.loop(); // Handle OTA updates
    tickTimer.reset();
  }

  if (checkTempTimer.isReady())
  {
    static int readCycle = 0; // 0-7 counter for 1Hz fan updates
    static double lastValidTemp = 0;
    static bool firstReading = true;
    static double lastValidFanTemp = 0;
    static bool firstFanReading = true;
    static int fanOverTempCount = 0;
    static bool fanTempSafetyArmedLogged = false;
    static bool fanTempSafetyDelayLogged = false;

    // Cycle 0, 2, 4, 6: Read Main Sensor (4 Hz)
    // Cycle 1, 3, 5, 7: Read Fan Sensor (4 Hz)
    // This ensures we never read both sensors in the same 125ms window
    if (readCycle % 2 == 0)
    {
      // Read thermocouple with failure detection
      double reading = thermocouple.readFarenheit();
      double previousAcceptedTemp = currentTemp;

      // 1. Range Check: MAX6675 returns ~2048°F when disconnected
      // We also check for negative values which are invalid for this application
      bool isRangeError = (reading < 0 || reading > SENSOR_FAULT_TEMP);
      if (isRangeError)
      {
        setLastRejectedBeanReadReason("range");
        LOG_WARNF("Temp range error ignored: raw=%.1fF accepted=%.1fF lastValid=%.1fF", reading, previousAcceptedTemp, lastValidTemp);
      }
      
      // 2. Spike Check: Ignore physically impossible temperature jumps
      bool isSpike = false;
      if (!isRangeError && !firstReading && shouldFilterBeanTempSpikes() && abs(reading - lastValidTemp) > MAX_TEMP_JUMP) {
        isSpike = true;
        setLastRejectedBeanReadReason("spike");
        LOG_WARNF("Temp spike ignored: lastValid=%.1fF raw=%.1fF accepted=%.1fF", lastValidTemp, reading, previousAcceptedTemp);
      }

      if (isRangeError || isSpike)
      {
        badReadingCount++;
        if (badReadingCount >= MAX_BAD_READINGS)
        {
          // SENSOR FAILURE - EMERGENCY STOP
          DEBUG_PRINTLN("EMERGENCY: Thermocouple failure detected!");
          String message = formatBeanSensorFaultMessage(reading);
          enterEmergencyErrorState("sensor_failed", message.c_str());
        }
      }
      else
      {
        currentTemp = reading;
        lastValidTemp = reading;
        firstReading = false;
        badReadingCount = 0; // Reset counter on good reading

        if (previousAcceptedTemp > 0.0) {
          bool suspiciousLowLatch = reading <= 40.0 && previousAcceptedTemp >= 80.0;
          bool largeAcceptedDrop = abs(reading - previousAcceptedTemp) >= 20.0;
          if (suspiciousLowLatch || largeAcceptedDrop) {
            LOG_WARNF("Bean temp accepted: prev=%.1fF raw=%.1fF new=%.1fF lastValid=%.1fF state=%d heater=%.1f", previousAcceptedTemp, reading, currentTemp, lastValidTemp, roasterState, heaterOutputVal);
          }
        }

        if (isRoastActiveState() && currentTemp > MAX_ROAST_TEMP)
        {
          DEBUG_PRINTLN("EMERGENCY: Roast temperature limit exceeded!");
          enterEmergencyErrorState("roast_over_temperature", "Roast Over Temp");
        }

        // THERMAL RUNAWAY PROTECTION
        if (roasterState != ERROR && currentTemp > MAX_SAFE_TEMP)
        {
          // EMERGENCY SHUTDOWN
          DEBUG_PRINTLN("EMERGENCY: Thermal runaway detected!");
          enterEmergencyErrorState("over_temperature", "Over Temp");
        }
      }
    }
    // Odd cycles: Read Fan Sensor (4 Hz)
    else
    {
      double fReading = thermocoupleFan.readFarenheit();
      const bool fanTempSafetyArmed = shouldEnforceFanTempSafety();
      bool isFanRangeError = (fReading <= 0 || fReading > SENSOR_FAULT_TEMP);
      if (isFanRangeError) {
        fanOverTempCount = 0;
        LOG_WARNF("Fan temp range error ignored: %.1f", fReading);
      }

      bool isFanSpike = false;
      if (!isFanRangeError && !firstFanReading && shouldFilterFanTempSpikes() && abs(fReading - lastValidFanTemp) > MAX_TEMP_JUMP) {
        isFanSpike = true;
        fanOverTempCount = 0;
        LOG_WARNF("Fan temp spike ignored: %.1f -> %.1f", lastValidFanTemp, fReading);
      }

      bool isImplausibleFanReading = false;
      if (!isFanRangeError && !isFanSpike && heaterOutputVal <= 0.0 && currentTemp < 140.0) {
        if (fReading > currentTemp + 30.0) {
          isImplausibleFanReading = true;
          fanOverTempCount = 0;
          LOG_WARNF("Fan temp implausible with heater off ignored: bean=%.1fF fan=%.1fF", currentTemp, fReading);
        }
      }

      if (!isFanRangeError && !isFanSpike && !isImplausibleFanReading) {
        fanTemp = fReading;
        lastValidFanTemp = fReading;
        firstFanReading = false;

        if (roasterState == ROASTING && !fanTempSafetyArmed) {
          if (roastStartedAtMs > 0 && !fanTempSafetyDelayLogged) {
            unsigned long warmupRemainingMs = FAN_TEMP_SAFETY_ARM_DELAY_MS;
            unsigned long elapsedRoastMs = millis() - roastStartedAtMs;
            if (elapsedRoastMs < FAN_TEMP_SAFETY_ARM_DELAY_MS) {
              warmupRemainingMs = FAN_TEMP_SAFETY_ARM_DELAY_MS - elapsedRoastMs;
            } else {
              warmupRemainingMs = 0;
            }

            LOG_INFOF("Fan temp safety delayed: remaining=%lums bean=%.1fF fan=%.1fF heater=%.1f",
                      warmupRemainingMs,
                      currentTemp,
                      fanTemp,
                      heaterOutputVal);
            fanTempSafetyDelayLogged = true;
          }
          fanTempSafetyArmedLogged = false;
        } else if (fanTempSafetyArmed && !fanTempSafetyArmedLogged) {
          LOG_INFOF("Fan temp safety armed: elapsed=%lus bean=%.1fF fan=%.1fF heater=%.1f threshold=%.1fF",
                    roastStartedAtMs > 0 ? (millis() - roastStartedAtMs) / 1000UL : 0UL,
                    currentTemp,
                    fanTemp,
                    heaterOutputVal,
                    MAX_SAFE_FAN_TEMP);
          fanTempSafetyArmedLogged = true;
        }

        // Require the over-temp reading to persist briefly so one noisy sample
        // cannot immediately trip the roaster into an error state.
        if (fanTempSafetyArmed && fanTemp > MAX_SAFE_FAN_TEMP) {
          fanOverTempCount++;
          LOG_WARNF("Fan temp over threshold (%d/3): %.1fF bean=%.1fF heater=%.1f elapsed=%lus",
                    fanOverTempCount,
                    fanTemp,
                    currentTemp,
                    heaterOutputVal,
                    roastStartedAtMs > 0 ? (millis() - roastStartedAtMs) / 1000UL : 0UL);
          if (fanOverTempCount >= 3) {
            DEBUG_PRINTLN("EMERGENCY: Fan/Exhaust Over Temp!");
            LOG_ERRORF("Fan temp safety trip: bean=%.1fF fan=%.1fF heater=%.1f elapsed=%lus threshold=%.1fF",
                       currentTemp,
                       fanTemp,
                       heaterOutputVal,
                       roastStartedAtMs > 0 ? (millis() - roastStartedAtMs) / 1000UL : 0UL,
                       MAX_SAFE_FAN_TEMP);
            enterEmergencyErrorState("fan_over_temperature", "Fan over temp");
          }
        } else {
          fanOverTempCount = 0;
        }
      }
    }

    readCycle = (readCycle + 1) % 8;
    // Metrics now available via debug console at /console
    checkTempTimer.reset();
  }

  if (controlLoopTimer.isReady())
  {
    unsigned long now = millis();
    updateRoastControl(now);
    updateCalibrationControl(now);
    controlLoopTimer.reset();
  }

  if (stateMachineTimer.isReady())
  {
    static RoasterState lastState = IDLE;
    if (roasterState != lastState) {
        LOG_INFOF("State transition: %d -> %d", lastState, roasterState);
        
        // Handle state entry logic
        if (roasterState == CALIBRATING) {
             // Stop PID to prevent interference
             resetRoastControllerState();
             
             // Initialize fan ramp
             fanRampStep = 0;
             
             LOG_INFO("Calibration: Starting fan ramp sequence");
        }
        
        lastState = roasterState;
    }
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

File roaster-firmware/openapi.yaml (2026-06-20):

openapi: 3.0.3
info:
  title: Coffee Roaster Control API
  description: |
    RESTful API for controlling and monitoring an ESP32-based coffee roaster.
    
    Features:
    - Real-time temperature monitoring
    - PID-controlled heating
    - Variable speed fan control
    - Profile-based roasting automation
    - WebSocket live data streaming
    
    Hardware:
    - ESP32 microcontroller
    - MAX6675 thermocouple sensors
    - PWM fan control
    - BDC servo fan control
    - Optional local display hardware for LVGL-enabled targets
  version: 1.0.0
  contact:
    name: Coffee Roaster Project
  license:
    name: MIT

servers:
  - url: http://roaster-dev.local
    description: mDNS hostname (requires Bonjour/Avahi)
  - url: http://192.168.1.100
    description: Direct IP address (replace with actual IP)

tags:
  - name: System
    description: System state and monitoring
  - name: Profiles
    description: Roast profile management (CRUD operations)
  - name: Debug
    description: Debug logging and diagnostics
  - name: UI
    description: Web user interfaces

paths:
  /api/state:
    get:
      tags: [System]
      summary: Get current system state
      description: Returns real-time roaster state including temperatures, control outputs, profile progress, and safety metrics.
      operationId: getSystemState
      responses:
        '200':
          description: System state retrieved successfully
          content:
            application/json:
              schema:
                $ref: '#/components/schemas/SystemState'
              example:
                timestamp: 1234567890
                state: "ROASTING"
                uptime: 3600
                temps:
                  current: 385.5
                  setpoint: 390.0
                  fan: 275.3
                control:
                  heater: 180
                  pwmFan: 128
                  bdcFan: 1200
                profile:
                  progress: 65
                  setpointCount: 5
                  finalTemp: 444
                safety:
                  badReadings: 0
                memory:
                  heapFree: 245760
                  heapSize: 327680

  /api/profiles:
    get:
      tags: [Profiles]
      summary: List all saved profiles
      description: Returns list of all profile names and the currently active profile.
      operationId: listProfiles
      responses:
        '200':
          description: Profile list retrieved successfully
          content:
            application/json:
              schema:
                $ref: '#/components/schemas/ProfilesList'
              example:
                profiles: ["Light Roast", "Medium Roast", "Dark Roast"]
                active: "Medium Roast"
    
    post:
      tags: [Profiles]
      summary: Create new profile
      description: Creates a new roast profile with default setpoints or provided configuration.
      operationId: createProfile
      requestBody:
        required: true
        content:
          application/json:
            schema:
              type: object
              properties:
                name:
                  type: string
                  maxLength: 13
                  description: Profile name (max 13 chars due to NVS key length limits)
                  example: "New Profile"
      responses:
        '201':
          description: Profile created successfully
          content:
            application/json:
              schema:
                $ref: '#/components/schemas/SuccessResponse'
        '400':
          description: Invalid request
          content:
            application/json:
              schema:
                $ref: '#/components/schemas/ErrorResponse'
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

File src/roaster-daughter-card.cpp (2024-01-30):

#ifdef NATIVE

int main(int argc, char **argv)
{
  int i = 0;
  return 0;
}

#else

#include "Arduino.h"
#include <EasyNextionLibrary.h>
#include <max6675.h>
#include <SimpleTimer.h>
#include <PWMrelay.h>
#include <AutoPID.h>
#include <SPI.h>
#include <EEPROM.h>
#include <Profiles.hpp>
#ifdef ARDUINO_ARCH_ESP32
#include <Network.hpp>
#include <Preferences.h>
Preferences preferences;
#endif

// #define DEBUG

#ifdef DEBUG
#define DEBUG_SERIALBEGIN(x) Serial.begin(x)
#define DEBUG_PRINT(x) Serial.print(x)
#define DEBUG_PRINTLN(x) Serial.println(x)

#else
#define DEBUG_SERIALBEGIN(x) // blank line
#define DEBUG_PRINT(x)       // blank line
#define DEBUG_PRINTLN(x)     // blank line
#endif

#ifdef ARDUINO_ARCH_ESP32
#define HW_SERIAL Serial0
#else
#define HW_SERIAL Serial
#endif

// Pin definitions
#define TC1_CS 10
#define HEATER A0
#define FAN A1

// PID settings and gains
#define OUTPUT_MIN 0
#define OUTPUT_MAX 255
#define KP 8.0
#define KI 0.46
#define KD 0

#define VERSION "2024-01-28"

// Use timers for simple multitasking
SimpleTimer checkTempTimer(250);
SimpleTimer tickTimer(5);
SimpleTimer stateMachineTimer(500);

// PWM is used to control fan and heater outputs
PWMrelay heaterRelay(HEATER, HIGH);
PWMrelay fanRelay(FAN, HIGH);

// Create a roast profile object
Profiles profile;

// Roaster state variables
double currentTemp = 0;
double setpointTemp = 0;
double heaterOutputVal = 0;
byte setpointFanSpeed = 0;
int setpointProgress = 0;

enum RoasterState
{
  IDLE = 0,
  START_ROAST = 1,
  ROASTING = 2,
  COOLING = 3,
  ERROR = 4
};

RoasterState roasterState = IDLE;

MAX6675 thermocouple(SCK, TC1_CS, MISO);
AutoPID heaterPID(&currentTemp, &setpointTemp, &heaterOutputVal, 0, 255, KP, KI, KD);

// Create a Nextion display connection
EasyNex myNex(HW_SERIAL);

// Default roast profile. Any changes stored in EEPROM will override these values.
void setDefaultRoastProfile()
{
  profile.clearSetpoints();
  profile.addSetpoint(150000, 300, 100);
  profile.addSetpoint(300000, 380, 90);
  profile.addSetpoint(480000, 440, 90);
}
uint8_t profileBuffer[200];

void setup()
{
  myNex.begin(115200);

  // Set heater and fan control pins to output
  pinMode(HEATER, OUTPUT);
  pinMode(FAN, OUTPUT);

  // Explicitly enable the pinMode for the SPI pins because the library doesn't appear to do this correctly when running on an ESP32
  pinMode(TC1_CS, OUTPUT);
  pinMode(SCK, OUTPUT);
  pinMode(MISO, INPUT);

  // Set output pins to safe state (LOW)
  digitalWrite(HEATER, LOW);
  heaterPID.setTimeStep(250);
  digitalWrite(FAN, LOW);
  fanRelay.setPeriod(10);

  setDefaultRoastProfile();
#ifdef ARDUINO_ARCH_ESP32
#elif ARDUINO_ARCH_AVR
  EEPROM.begin();
#endif

#ifdef ARDUINO_ARCH_ESP32
WifiCredentials wifiCredentials;
  preferences.begin("roaster", false);
  wifiCredentials.ssid = preferences.getString("ssid", "");
  wifiCredentials.password = preferences.getString("password", "");
  String ipAddress = initializeWifi(wifiCredentials);
  if (ipAddress != "Failed to connect to WiFi")
  {
    preferences.putString("ssid", wifiCredentials.ssid);
    preferences.putString("password", wifiCredentials.password);
  }
#endif

  // EEPROM.get(0, profileBuffer);
  preferences.getBytes("profile", profileBuffer, 200);
  profile.unflattenProfile(profileBuffer);

  myNex.writeNum("ConfigSetpoint.spTemp1.val", profile.getSetpoint(1).temp);
  myNex.writeNum("ConfigSetpoint.spTemp1.val", profile.getSetpoint(1).temp);
  myNex.writeNum("ConfigSetpoint.spTemp2.val", profile.getSetpoint(2).temp);
  myNex.writeNum("ConfigSetpoint.spTemp3.val", profile.getSetpoint(3).temp);
  myNex.writeNum("ConfigSetpoint.spTime1.val", profile.getSetpoint(1).time / 1000);
  myNex.writeNum("ConfigSetpoint.spTime2.val", profile.getSetpoint(2).time / 1000);
  myNex.writeNum("ConfigSetpoint.spTime3.val", profile.getSetpoint(3).time / 1000);
  myNex.writeNum("ConfigSetpoint.spFan1.val", profile.getSetpoint(1).fanSpeed);
  myNex.writeNum("ConfigSetpoint.spFan2.val", profile.getSetpoint(2).fanSpeed);
  myNex.writeNum("ConfigSetpoint.spFan3.val", profile.getSetpoint(3).fanSpeed);
  myNex.writeStr("ConfigWifi.ip.txt", ipAddress);
  myNex.writeStr("ConfigNav.rev.txt", VERSION);

  myNex.writeStr("page Start");

  DEBUG_PRINTLN("Setup complete");
}

void loop()
{
  if (tickTimer.isReady())
  {
    myNex.NextionListen();
    heaterRelay.tick();
    fanRelay.tick();
    heaterPID.run();
    wsCleanup();
    tickTimer.reset();
  }

  if (checkTempTimer.isReady())
  {
    currentTemp = thermocouple.readFarenheit();
    DEBUG_PRINT("Temp: ");
    DEBUG_PRINTLN(currentTemp);
    DEBUG_PRINT("Fan speed: ");
    DEBUG_PRINTLN(setpointFanSpeed);
    DEBUG_PRINT("Heater output: ");
    DEBUG_PRINTLN(heaterOutputVal);
    DEBUG_PRINT("Setpoint temp: ");
    DEBUG_PRINTLN(setpointTemp);
    DEBUG_PRINT("Setpoint progress: ");
    DEBUG_PRINTLN(setpointProgress);

    checkTempTimer.reset();
  }

  if (stateMachineTimer.isReady())
  {
    switch (roasterState)
    {
    case IDLE:
      // heaterRelay.setPWM(0);
      // fanRelay.setPWM(0);
      digitalWrite(HEATER, LOW);
      digitalWrite(FAN, LOW);
      heaterPID.stop();
      heaterOutputVal = 0;
      break;

    case START_ROAST:
      DEBUG_PRINTLN("Start roast");
      roasterState = ROASTING;

      fanRelay.setPWM(profile.getTargetFanSpeed(millis()));
      delay(500);
      profile.startProfile((int)currentTemp, millis());
      heaterPID.run();
      heaterRelay.setPWM(heaterOutputVal);

      sendWsMessage("{ \"pushMessage\": \"startRoasting\" }");

      profile.flattenProfile(profileBuffer);
      preferences.putBytes("profile", profileBuffer, 200);
      // EEPROM.put(0, profileBuffer);
      break;

    case ROASTING:
      setpointTemp = profile.getTargetTemp(millis());
      setpointFanSpeed = profile.getTargetFanSpeed(millis());
      setpointProgress = profile.getProfileProgress(millis());

      fanRelay.setPWM(setpointFanSpeed);
      heaterRelay.setPWM(heaterOutputVal);

      if (currentTemp >= profile.getFinalTargetTemp())
      {
        heaterPID.stop();
        heaterOutputVal = 0;
        heaterRelay.setPWM(heaterOutputVal);
        // digitalWrite(HEATER, LOW);

        setpointTemp = 145;
        roasterState = COOLING;

        setpointFanSpeed = 255;
        fanRelay.setPWM(setpointFanSpeed);

        setpointProgress = 0;
        myNex.writeStr("page Cooling");
        DEBUG_PRINTLN("Roast complete -> cooling");
      }
      myNex.writeNum("globals.currentTempNum.val", (int)currentTemp);
      myNex.writeNum("globals.nextSetTempNum.val", setpointTemp);
      myNex.writeNum("globals.setpointFan.val", round(setpointFanSpeed * 100 / 255));
      myNex.writeNum("globals.setpointProg.val", setpointProgress);
      break;

    case COOLING:
      digitalWrite(HEATER, LOW);
      myNex.writeNum("globals.currentTempNum.val", (int)currentTemp);
      DEBUG_PRINTLN("Cooling");
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

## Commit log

2024-01-23 add PID control
2024-01-29 Add PCB files and readme updates
    [Roaster Control - Rev I.brd, Roaster Control - Rev I.dxf, Roaster Control - Rev I.sch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]
2024-09-11 3d printing files
    [Enclosure Bottom.stl, Enclosure Top.stl, Feet.stl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]
2024-12-11 Assembly instructions and IDE migration
    [Cube.stl, PCB Standoff.stl, Power Supply mount.stl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]
2025-12-22 BDC motor support + testing
2025-12-25 Nextion ProfileActive improvements: plot full profile on waveform (480x170) with component ID 2, corrected x-axis orientation; seed and honor final temp override via Nextion; add trigger4() to plot o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
    [Network.hpp, ProfileEditor.hpp, Profiles.hpp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]
2026-05-04 feat: onset dead time autotuner + remove sawtooth tuner
    Step-response autotuner improvements:
    - Add onset dead time detector (3σ noise threshold) for more accurate
    SIMC tuning on higher-order thermal systems where FOPDT dead time is
    inflated. Uses measured response onset instead of model-fitted θ.
    - Populate feedforward model parameters (heaterCoeff, coolingCoeff,
    drift) from FOPDT model in both autotuner paths, fixing broken
    feedforward that was dividing by zero.
    - Add noise σ measurement during stabilization phase.
    - Include onsetDeadTime and noiseSigma in SystemLink calibration CSV
    and test result properties.
    Sawtooth autotuner removal:
    - Delete PIDAutotuner.hpp (legacy sawt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
    [Network.hpp, PIDController.hpp, PIDRuntimeController.hpp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]
2026-05-04 feat: add agent skills, web UI updates, tests, and SystemLink notebooks
    Agent skills:
    - nipkg-file-package: NI Package Manager file packaging
    - slcli: SystemLink CLI reference (refactored with sub-references)
    - systemlink-job-debugging: Salt job debugging guide
    - systemlink-notebook: Jupyter notebook creation for SystemLink
    - systemlink-python-test: Python test integration with SystemLink
    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
    [roaster-pid-advisor-raw.json]
2026-05-04 remove conversion notebook
    [roaster-pid-advisor-raw.json]
2026-05-04 ci: cache Arduino deps and avoid duplicate builds
2026-05-08 fix: make Arduino CLI config init idempotent
2026-05-08 redesign: clean project page with categorized content and parts list
    - Replace marketing-heavy copy with direct project descriptions
    - Add categorized 'What's in the repo' cards (3D printing, PCB, firmware, popper mod)
    - Add full parts list table with purchase links
    - Switch to Inter font, minimal borders, no decorative effects
    - Use real build photos throughout
    - Add safety section and build steps with numbered layout
2026-06-19 print files, firmware bringup, testing
    [Roaster Breakout.brd, Roaster Breakout.sch]
2026-06-19 cleanup and doc update
    [12V - Power Supply Mount.stl, Breakout Mount.stl, Cube.stl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]
2026-06-19 Tighten v2 documentation consistency
2026-06-20 site updates and pcb labeling
    [Roaster Breakout.brd]
2026-09-03 resistive display support
    [Roaster Enclosure v2.3mf]
2026-09-03 bom update
2026-09-03 bom updates
2026-09-16 Speed up Arduino firmware builds

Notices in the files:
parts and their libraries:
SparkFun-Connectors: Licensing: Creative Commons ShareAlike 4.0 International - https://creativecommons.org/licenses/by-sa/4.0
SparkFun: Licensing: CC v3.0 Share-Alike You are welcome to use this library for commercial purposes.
